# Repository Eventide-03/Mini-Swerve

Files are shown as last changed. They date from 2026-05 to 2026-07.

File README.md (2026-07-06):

# Swerve Drivetrain

A fully custom four-module swerve drivetrain built to replicate the FRC/FTC swerve drivetrains. Every part of this project was designed/planned by me.

## Project Resources

- **[CAD (Onshape)](https://cad.onshape.com/documents/22f3425ea7c3c5baea4db72a/w/41cf12666249611bfbd4a57b/e/570cbec20c3995e10be4fe6f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)** — full mechanical assembly and exploded views
- **[Bill of Materials (Google Sheets)](https://docs.google.com/spreadsheets/d/13JzB3kvO0vG1ZuJ61luXd1x6dMnEUsCQSgEZeQXHTig/edit?usp=sharing)** — every part, quantity, and source
- **[Calculations (Google Docs)](https://docs.google.com/document/d/1093Fhib_KALhrss7tIt823cWR-YH7OZk02LRxrgmfjs/edit?usp=sharing)** — gear ratios, motor sizing, and drivetrain math

## Overview

Swerve drive is an omnidirectional drivetrain, which means each wheel module can independently steer and drive, allowing a robot to move and rotate at the same time. I thought it would be nice to make a tinier at-home version for my own enjoyment, normally they are pretty big, but this one is fun sized.

This build has the full swerve control system on a 12.25 × 12.25 inch chassis with four independent modules. Each module uses 5010 brushless motors for driving and steering, using gear reductions to achieve the required torque. This leaves us with a miniature platform that actslike a full-size competition swerve, but small enough to use in my own house.

In order to save money I designed a custom PCB in order to hold everything, making it much easier to wire. In addition I will be using my SpeedyBee f405 to control the drive motors to avoid having to pay for 4 extra motor controllers.

## Specifications

| Attribute | Detail |
|---|---|
| Chassis footprint | 12.25 × 12.25 in |
| Modules | 4 (independent steer + drive) |
| Motors | 8 × 5010 360 kV brushless (4 drive, 4 steer) |
| Reduction | 8:1 per axis |
| Master controller | ESP32-S3-DevKitC-1 |
| Steering control | 2 × Makerbase (MKS) ESP32 Dual FOC ESC, controlled over UART via SimpleFOC Commander |
| Drive control | SpeedyBee F405 4-in-1 ESC (DSHOT600) |
| Steering feedback | 4 × AS5600 magnetic encoders (I²C) |
| Radio control | RadioMaster Pocket ELRS (TX + receiver) |
| Power | 4S LiPo (14.8 V) → Mini-360 buck converter (5 V) for logic |

## Architecture

The ESP32-S3-DevKitC-1 runs most of the code and is the brain reading commands from the ELRS receiver, and running the swerve kinematics, and sending the commands to the two motor-control subsystems:

- **Driving:** The master sends DSHOT600 signals to the SpeedyBee F405 4-in-1 ESC, which drives the four drive motors.
- **Steering:** The master sends addressed commands over a shared UART bus to two MKS ESP32 Dual FOC boards (using [SimpleFOC](https://simplefoc.com/) Commander). Each board runs field-oriented control on two steering motors, using an AS5600 magnetic encoder per module for absolute angle feedback.

All of this lives on the carrier PCB that seats the ESP32-S3 and breaks out clean, labeled connectors for the ESC, MKS boards, encoders, receiver, and power.

> **Important:** The steering magnets must be diametrically magnetized (poles across the diameter, not top-to-bottom), 6 × 2.5 mm, and mounted on the steering rotation axis, not the motor shaft or drive shaft. The AS5600 reports an absolute 0–360°, so it must rotate 1:1 with the module's steering angle.

---

## Assembly Instructions

Work through these in order. Use the **[CAD exploded views](https://cad.onshape.com/documents/22f3425ea7c3c5baea4db72a/w/41cf12666249611bfbd4a57b/e/570cbec20c3995e10be4fe6f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)** go to the assembly and click the exploded views to the left.

### 1. Gather parts
Order everything on the **[BOM](https://docs.google.com/spreadsheets/d/13JzB3kvO0vG1ZuJ61luXd1x6dMnEUsCQSgEZeQXHTig/edit?usp=sharing)** and 3D-print the printed components from the CAD. Confirm you have all fasteners, belts, bearings, and magnets before starting.

### 2. Populate and solder the PCB
- Solder the through-hole headers and connectors to the custom carrier board, following the silkscreen labels.
- Solder the decoupling capacitors near the ESP32 5 V pin.
- Solder the pin-socket rows that the ESP32-S3-DevKitC-1 plugs into.
- **Before powering anything, use a multimeter to verify there are no shorts** between 5 V, GND, and the battery rails.

### 3. Wire the drive ESC (SpeedyBee F405)
- Connect the four drive-motor signal lines and a shared ground from the SpeedyBee ESC to the DSHOT header on the carrier board.
- Use only the M1–M4 signal pads plus one GND pad (verify GND with a multimeter first — M5–M8 pads on the board have no hardware behind them).

### 4. Wire the steering controllers (MKS ESP32 Dual FOC)
- Connect each MKS board's UART (TX/RX/GND) to the shared steering UART nets on the carrier board.
- Both boards share the bus and are addressed individually in firmware via SimpleFOC Commander.

### 5. Set up the encoders (AS5600)
- Mount each AS5600 so its chip faces the diametrically-magnetized magnet on the **steering rotation axis** of each module.
- Wire each encoder's VCC / GND / SDA / SCL to its MKS board's encoder header, and tie DIR to GND.
- Before final assembly, flash SimpleFOC firmware to the MKS boards, configure the motors, and run encoder calibration for each module.

### 6. Assemble the mechanical drivetrain
- Build the four swerve modules and mount them to the chassis per the **[CAD exploded views](https://cad.onshape.com/documents/22f3425ea7c3c5baea4db72a/w/41cf12666249611bfbd4a57b/e/570cbec20c3995e10be4fe6f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)**.
- Install belts, bearings, and wheels; verify each module steers freely and each drive wheel spins without binding.

### 7. Power distribution
- Wire the 4S LiPo through the switch and fuse, then split to the SpeedyBee ESC, both MKS boards, and the Mini-360 buck converter input.
- The buck's 5 V output feeds the carrier board's logic rail (ESP32 + receiver). **The battery's 14.8 V never reaches the carrier board directly** — only the buck input does.

### 8. Flash the ESP32-S3 and bring it up
- Open the firmware in **[Arduino IDE 2.x](https://www.arduino.cc/en/software)** and select the **ESP32S3 Dev Module** board.
- Bring the system up progressively rather than all at once:
  1. **Smoke test** — confirm the board powers and blinks.
  2. **Drive test** — verify DSHOT control of a single drive motor.
  3. **Steering test** — send a UART target to an MKS board and confirm the steering motor holds position.
  4. **Receiver test** — confirm the ESP32 reads ELRS channels.
- Once each subsystem checks out, run the full firmware to read the transmitter, compute swerve kinematics, and drive all eight motors together.

---

## Notes

- Some ESP32-S3-DevKitC-1 revisions have different row spacing (22.86 mm vs 25.4 mm), measure your board with calipers before finalizing the PCB.
- Measure the Mini-360 buck module's pad spacing with calipers as well before ordering the board.
- The library APIs (DSHOT, SimpleFOC, ELRS) may need small adjustments to match current versions, adapt from each library's examples.






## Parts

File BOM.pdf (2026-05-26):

Item | Amount | Unit Price | Total | Justification | Link

MCMASTER CARR

33t belt | 4 | $9.92 | $39.68 | motors to gears | https://www.mcmaster.com/products/belts/timing-belts-1~/timing-belts-1~tooth-profile~modified-curved-gt/pitch~3-mm/width~9-mm/number-of-teeth~33/number-of-teeth~55/
55t belt | 4 | $10.59 | $42.36 | motors to gears | https://www.mcmaster.com/products/belts/timing-belts-1~/timing-belts-1~tooth-profile~modified-curved-gt/pitch~3-mm/width~9-mm/number-of-teeth~33/number-of-teeth~55/

REV ROBOTICS

Wheels | 4 | $5.50 | $22.00 | Wheels for swerve | https://www.revrobotics.com/rev-21-3004/
1/2 in bearing | 1 | $13.00 | $13.00 | Spinning wheels | https://www.revrobotics.com/ION-Bearings/

MAKERBASE3D

MKS ESP32 FOC | 2 | $25.99 | $51.98 | brushless motor controller for steering motors via uart https://makerbase3d.com/product/esp32-foc/

AMAZON

Motors | 2 | $71.59 | $143.18 | spinny | https://www.amazon.com/GoolRC-Brushless-MultiCopter-Quadcopter-Multi-axis/dp/B0C2YRNX1Z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
ESP32 | 1 | $15.00 | $15.00 | brain/motherboard | https://www.amazon.com/Espressif-ESP32-S3-DevKitC-1-N8R8-Development-Board/dp/B09MHP42LY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
8mm m3 bolts | 1 | $5.99 | $5.99 | mounting electrical and motors https://www.amazon.com/Thread-Socket-Button-Machine-Assortment/dp/B0FLKCP52N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
BEC Buck Converter | 1 | $8.69 | $8.69 | convert from battery to 5V power line https://www.amazon.com/Regulator-Reducer-4-75-23V-Converter-Mini360/dp/B0F1WB3LJ5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
AS5600 Encoders | 1 | $9.99 | $9.99 | encoders for steering (necessary for orientation), comes with magnets https://www.amazon.com/WWZMDiB-Measurement-Module%EF%BC%8CMainly-Information-Progressive/dp/B0CM3C8KFT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
Pin headers | 1 | $4.99 | $4.99 | connecting electronicshttps://www.amazon.com/QSYZAIL-Right-Angle-Connector-Compatible-Breadboard/dp/B0G56RWP5D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
2 Pair XT60 Connector Female/Male W/Housing 10CM Silicon Wire 14AWG | 1 | $6.99 | $6.99 | connecting electronicshttps://www.amazon.com/Padarsey-Connector-Female-Housing-Silicon/dp/B07BF8154S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
ATC Fuse Holders | 1 | $7.99 | $7.99 | prevent board from exploding https://www.amazon.com/Anyongora-Inline-Waterproof-Automotive-Standard/dp/B0CL7MLY6T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
14 AWG Silicone Wire | 1 | $9.88 | $9.88 | connecting electronicshttps://www.amazon.com/Electrical-Silicone-Flexible-Temperature-Resistance/dp/B0746H96QK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
22 AWG Silicone Wire | 1 | $11.48 | $11.48 | connecting electronicshttps://www.amazon.com/BNTECHGO-Flexible-Conductor-Resistant-Extension/dp/B077XBWX8V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

OTHER

Carrier Board | 1 | $9.80 | $9.80 $403.00 | hold electronics
Cost | Shipping | Total | BUYING WITH HCB CARD | BUYING MYSELF (over $400 limit)
MCMASTER CARR | $82.04 | $26.09 | $108.13 | $108.13 | $0.00
REV ROBOTICS | $35.00 | $19.00 | $54.00 | $0.00 | $54.00
MAKERBASE3D | $51.98 | $0.00 | $51.98 | $51.98 | $0.00
AMAZON | $224.18 | $24.13 | $248.31 | $238.43 | $9.88
JLCPCB | $9.80 | $5.21 | $15.01 | $0.00 | $15.01
$477.43 | $477.43 | $398.54 | $78.89 | $477.43

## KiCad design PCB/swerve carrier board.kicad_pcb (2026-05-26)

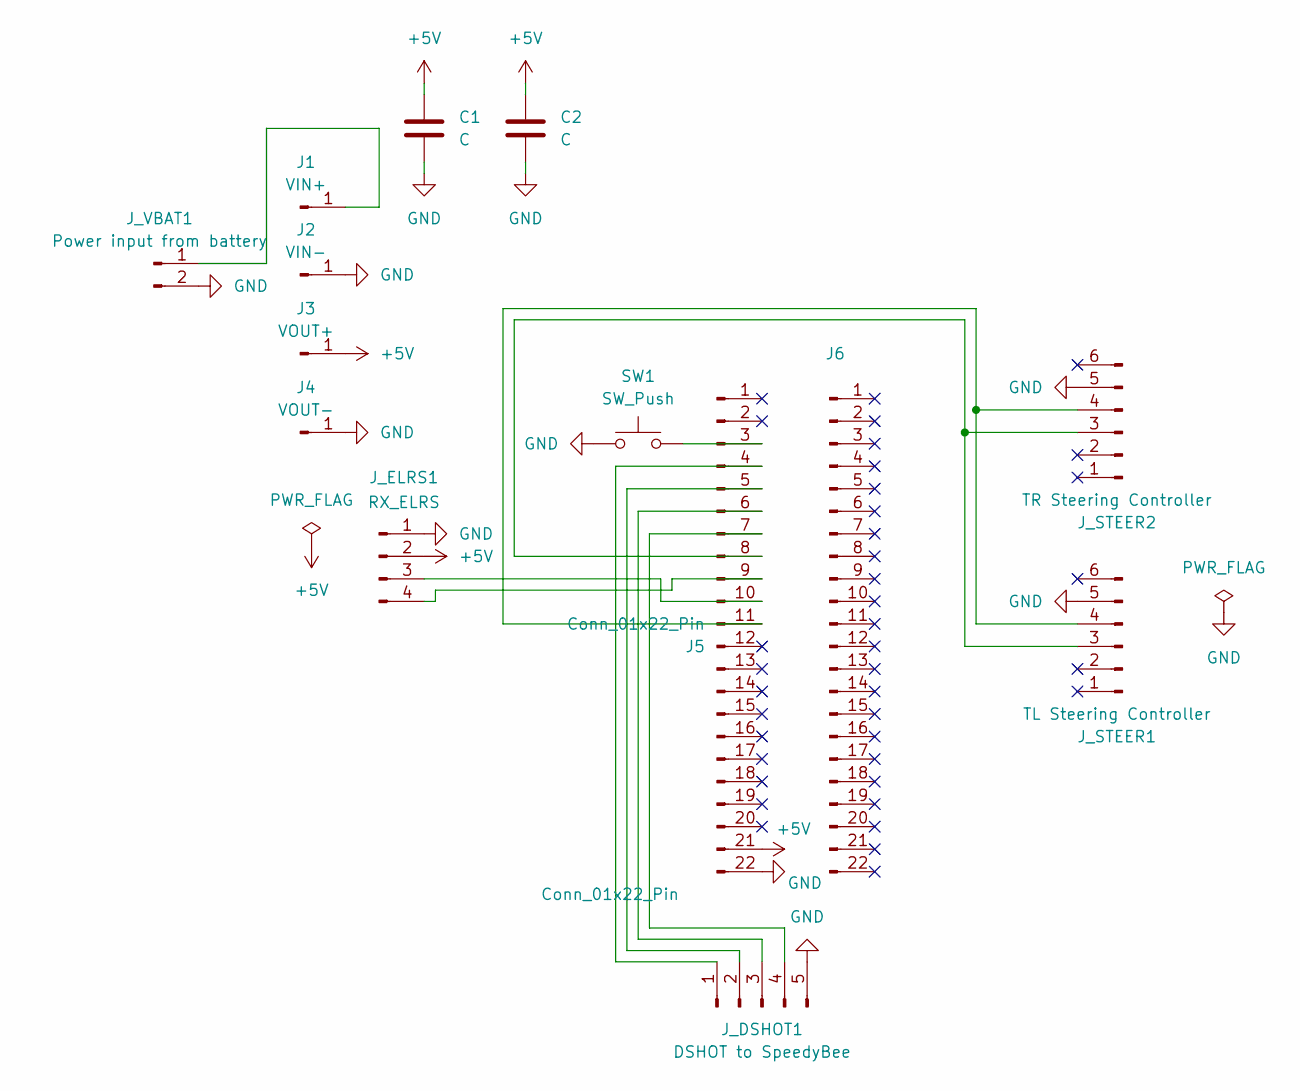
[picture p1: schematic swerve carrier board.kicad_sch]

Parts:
C1, C2: C; CP_Radial_D5.0mm_P2.50mm
J1: VIN+; PinHeader_1x01_P2.54mm_Vertical
J2: VIN-; PinHeader_1x01_P2.54mm_Vertical
J3: VOUT+; PinHeader_1x01_P2.54mm_Vertical
J4: VOUT-; PinHeader_1x01_P2.54mm_Vertical
J5: Conn_01x22_Pin; PinSocket_1x22_P2.54mm_Vertical_SMD_Pin1Left
J6: Conn_01x22_Pin; PinSocket_1x22_P2.54mm_Vertical_SMD_Pin1Right
J_DSHOT1: DSHOT to SpeedyBee; PinHeader_1x05_P2.54mm_Vertical
J_ELRS1: RX_ELRS; PinHeader_1x04_P2.54mm_Vertical
J_STEER1: TL Steering Controller; PinHeader_1x06_P2.54mm_Vertical
J_STEER2: TR Steering Controller; PinHeader_1x06_P2.54mm_Vertical
J_VBAT1: Power input from battery; PinHeader_1x02_P2.54mm_Vertical
SW1: SW_Push; SW_Cherry_MX_1.00u_PCB

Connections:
+5V: C1.1, C2.1, J3.1 (Pin_1_1), J5.21, J_ELRS1.2
GND: C1.2, C2.2, J2.1 (Pin_1_1), J4.1 (Pin_1_1), J5.22, J_DSHOT1.5, J_ELRS1.1, J_STEER1.5, J_STEER2.5, J_VBAT1.2, SW1.1
unnamed: J1.1 (Pin_1_1), J_VBAT1.1
unnamed: J5.3, SW1.2
unnamed: J5.4, J_DSHOT1.1
unnamed: J5.5, J_DSHOT1.2
unnamed: J5.6, J_DSHOT1.3
unnamed: J5.7, J_DSHOT1.4
unnamed: J5.8, J_STEER1.3, J_STEER2.3
unnamed: J5.9, J_ELRS1.4
unnamed: J5.10, J_ELRS1.3
unnamed: J5.11, J_STEER1.4, J_STEER2.4

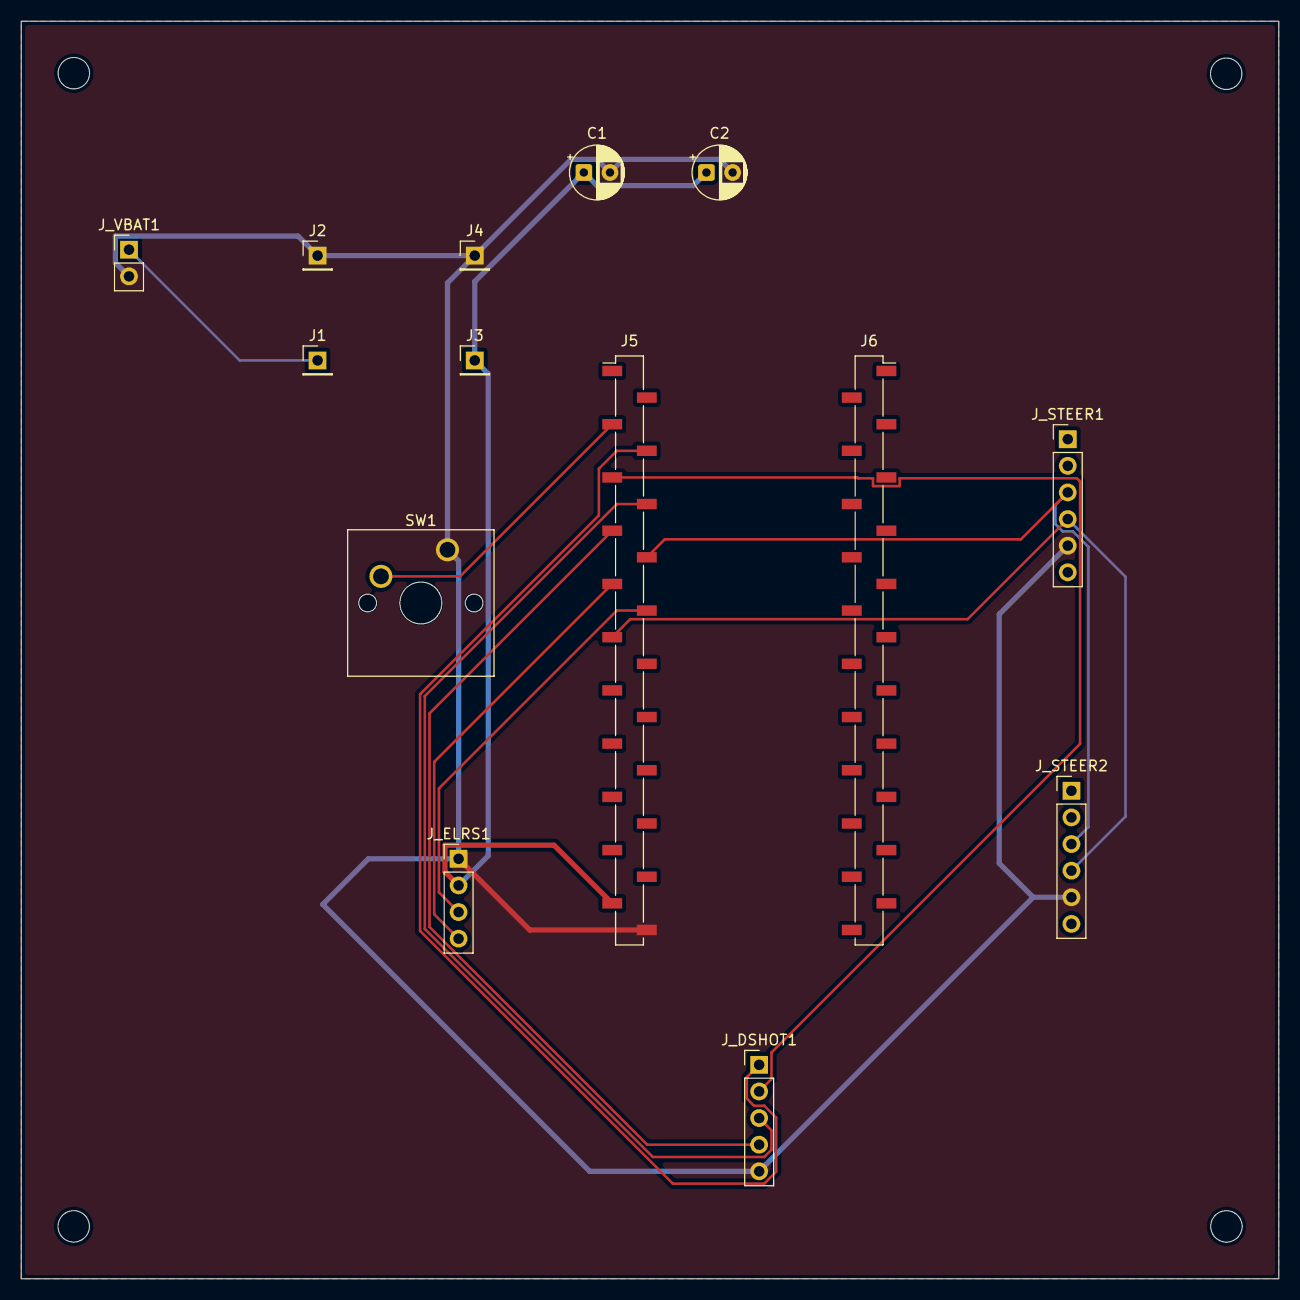
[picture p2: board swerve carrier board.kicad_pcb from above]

Board: 2 copper layers, 120.0 x 120.0 mm, 14 parts (0 on the bottom side), 12 nets.

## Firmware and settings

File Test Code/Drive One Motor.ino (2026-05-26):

#include <DShotRMT.h>

#define MOTOR1_PIN 4

DShotRMT motor1(MOTOR1_PIN, DSHOT600);

void setup() {
  Serial.begin(115200);
  delay(2000);
  Serial.println("DSHOT test starting");

  motor1.begin();
  delay(1000);

  Serial.println("Arming ESC...");
  for (int i = 0; i < 100; i++) {
    motor1.send_dshot_value(0);
    delay(10);
  }
}

void loop() {
  Serial.println("Ramping up...");
  for (int throttle = 48; throttle < 300; throttle += 2) {
    motor1.send_dshot_value(throttle);
    delay(50);
  }

  Serial.println("Ramping down...");
  for (int throttle = 300; throttle > 48; throttle -= 2) {
    motor1.send_dshot_value(throttle);
    delay(50);
  }

  Serial.println("Idle for 2 seconds...");
  for (int i = 0; i < 200; i++) {
    motor1.send_dshot_value(0);
    delay(10);
  }
}

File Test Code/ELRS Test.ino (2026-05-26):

#include <CRSFforArduino.hpp>

#define ELRS_RX 16
#define ELRS_TX 17
CRSFforArduino crsf = CRSFforArduino(&Serial2, ELRS_RX, ELRS_TX);

void setup() {
  Serial.begin(115200);
  delay(2000);
  Serial.println("ELRS test starting");

  if (!crsf.begin()) {
    Serial.println("CRSF init failed!");
    while (1) delay(100);
  }
  Serial.println("CRSF initialized");
}

void loop() {
  crsf.update();

  // Channels are 1-16 in CRSF
  // Standard mode 2: ch1=roll, ch2=pitch, ch3=throttle, ch4=yaw
  uint16_t roll = crsf.getChannel(1);
  uint16_t pitch = crsf.getChannel(2);
  uint16_t throttle = crsf.getChannel(3);
  uint16_t yaw = crsf.getChannel(4);

  Serial.printf("Roll:%4d Pitch:%4d Throttle:%4d Yaw:%4d\n",
                roll, pitch, throttle, yaw);
  delay(100);
}

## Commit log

2026-05-14 Add CAD document link to README
    Added a link to the CAD document for the project.
2026-05-17 Create Swerve Assembly.step
2026-05-17 Update README with CAD and BOM links
    Added links to CAD and BOM resources.
2026-05-26 added pcb files
    [swerve carrier board-B_Cu.gbr, swerve carrier board-B_Mask.gbr, swerve carrier board-B_Paste.gbr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]
2026-05-26 added bom
2026-05-26 Enhance README with design details and images
    Added additional details about the mini swerve design, including dimensions, images, and links to CAD and BOM.
2026-07-06 Revise README for Swerve Drivetrain project
    Updated the README to provide detailed information about the swerve drivetrain project, including specifications, architecture, and assembly instructions.
